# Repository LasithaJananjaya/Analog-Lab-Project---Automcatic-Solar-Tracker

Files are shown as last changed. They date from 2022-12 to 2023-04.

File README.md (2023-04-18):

# lab_project_solar_tracker
Semester 3 Analog Lab Project - Automatic Solar Tracker

## Abstract
This project aims to address the challenge of optimizing solar panel energy generation, given that the efficiency of current solar technology is affected by the intensity of sunlight and angle of incidence. The demand for solar power has increased worldwide as a preferred green energy alternative to non-renewable energy sources. To achieve the highest efficiency, an analog PID control circuit is designed to dynamically adjust the angular position of a solar panel along a single axis. This will enable the panel to optimize its generation of electricity, even under varying lighting and positional circumstances.

## Introduction
In contemporary times, the global community has been fervently exploring alternative energy sources, with a keen focus on renewable sources that can mitigate the adverse environmental impact of traditional energy sources. Among the plethora of renewable energy sources, solar energy has emerged as one of the most abundant and clean sources of energy on the planet. The harnessing of solar energy can be achieved through two main methods, namely, photovoltaic (PV) cells and solar thermal systems. Solar panels, which typically contain multiple solar cells, are employed to generate electricity using solar energy. These panels are installed in locations that receive direct sunlight, such as rooftops or solar farms, which may contain millions of solar panel arrays in desert areas. The utilization of solar energy through these methods offers significant potential to contribute to sustainable development and reduce dependence on non-renewable energy sources. 

A significant challenge facing solar panel technology is the inherent limitation that the maximum efficiency can only be achieved when the panel receives direct sunlight, i.e. when light strikes the panel perpendicularly. This constraint restricts the optimal efficiency of the panel to specific time periods during the day when the angle of incidence of the sun’s rays is perpendicular to the panel.

To overcome this constraint and enhance the efficiency of solar panels throughout the day, automatic solar trackers have emerged as a potential solution. These trackers are designed to enable solar panels to automatically align with direct sunlight, thereby maximizing the energy capture potential of the panel.

The incorporation of automatic solar trackers represents a significant advance in solar panel technology, enabling panels to achieve greater efficiency and reducing the environmental impact of energy production. By automatically adjusting the panel’s orientation to align with the sun’s rays, solar trackers offer a practical and effective means of maximizing energy output and promoting sustainable energy practices.

## Functionality Description
First, the two **LDR sensors** sense the intensity of the light that directly falls on. According to those parameters the resistances of the two sensors are varied. According to the design, if the resistance values of the two sensors are equal, the panel should remain still and if there is a difference, the panel should turn accordingly to reduce that difference. The panel is rotated using a motor and the motor is driven by a **PWM Control Signal**. If the duty of the PWM signal is 50%, the motor is not driven. Otherwise, the motor is driven in the required direction. The smooth operation of the motor is ensured by the **PID Controller**.

## System model
### Block Diagram

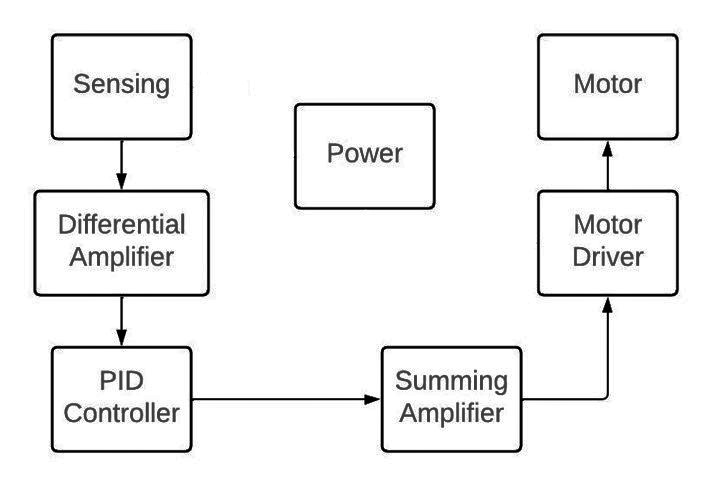
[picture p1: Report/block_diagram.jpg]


### Design Parameters
* Operating Voltage - 12 V
* Reference Voltage - 6 V
* Light Sensor - 12 mm LDR
* LDR Dark Resistance - 1MΩ
* LDR Light Resistance - 5 - 10 kΩ
* OPAMP Selection - UA741CP, LMC660CN and TLC372CP
* Motor Driver - L298N
* Motor - RK-370CA-18260 DC Motor
* Motor Stall Current - 300 mA
* PCB - 4 Layer, Manufactured and imported from JLC PCB (China)
* Enclosure Material - Wood

## Schematic

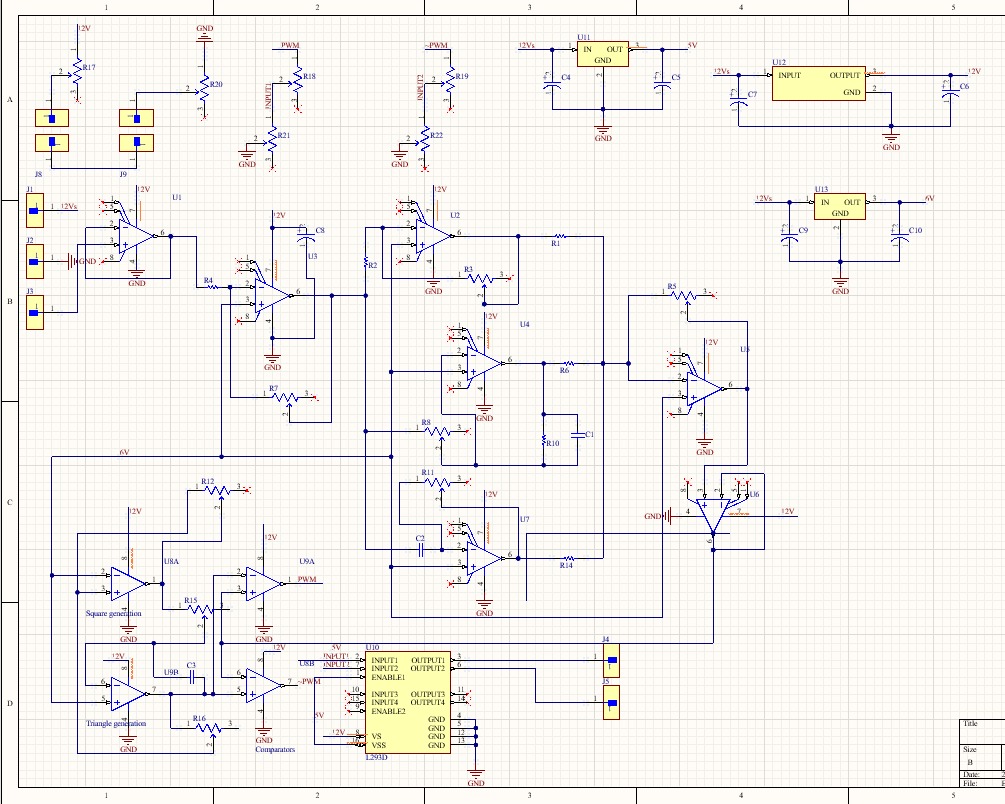
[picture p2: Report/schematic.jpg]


### Difference Amplifier
The difference between the input voltage and the set point voltage of 6 volts is being amplified

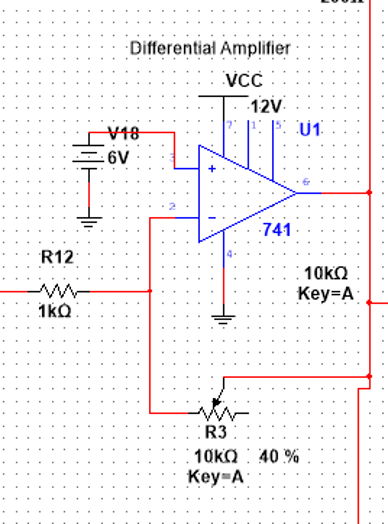
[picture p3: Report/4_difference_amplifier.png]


### PID Controller - Proportional Part

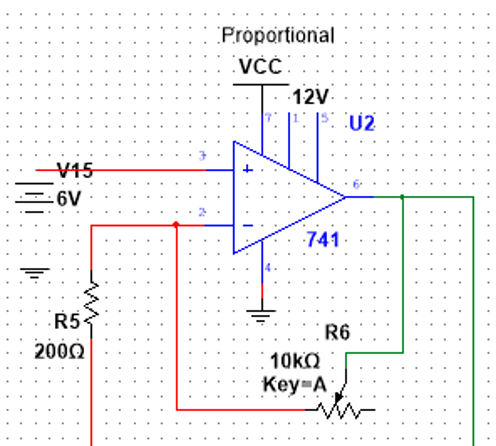
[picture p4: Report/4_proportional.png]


### PID Controller - Integral Part

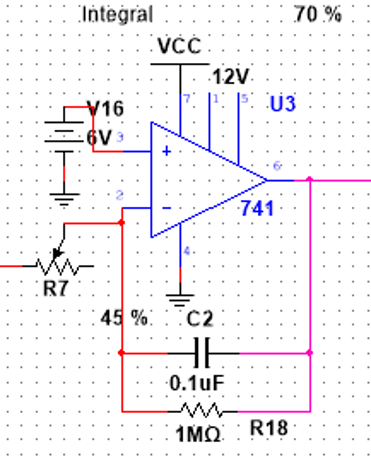
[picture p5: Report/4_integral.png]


### PID Controller - Derivative Part

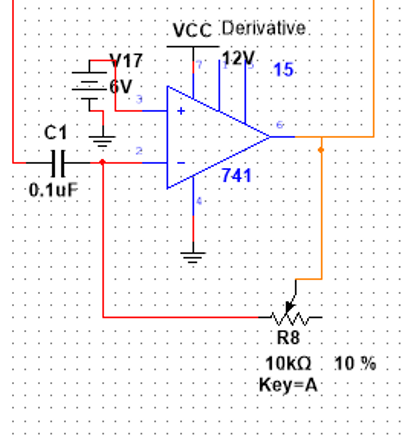
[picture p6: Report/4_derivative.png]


### Weighted Summing Amplifier
The Proportional-Integral-Derivative (PID) controller outputs are weighted and combined using appropriate algorithm. Specifically, larger resistors are incorporated into the design of the I and D controllers to ensure their effect on the overall operation of the PID controller is suitably reduced. This measure is essential for achieving a stable and effective PID control system.

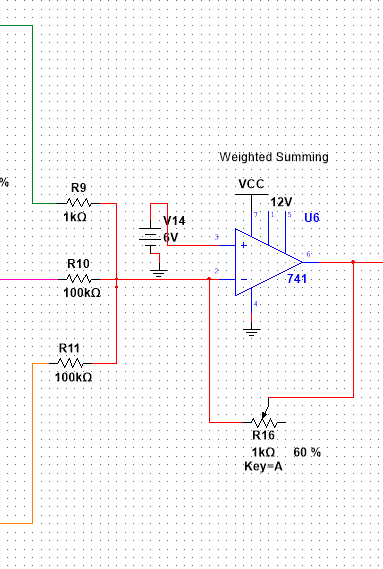
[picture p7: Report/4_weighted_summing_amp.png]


### Voltage Buffers
Voltage buffers have been employed to provide isolation between the input stage and output stage. To accomplish this, we have utilized an operational amplifier with a higher input impedance. This strategic implementation aims to minimize the loading effect and signal distortion that may occur between the two stages, thus ensuring optimal performance of the circuit. The incorporation of voltage buffers and an operational amplifier with higher input impedance serves to enhance the overall reliability and robustness of the circuit, while simultaneously minimizing potential signal loss and distortion.

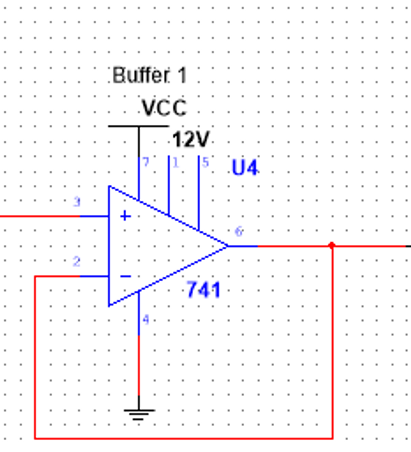
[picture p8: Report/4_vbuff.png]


### Triangular Wave Generation
The generation of a triangular waveform within the range of 0-12V and with a frequency of 500Hz is accomplished through the utilization of a Schmitt trigger and an integrator circuit. Specifically, the frequency of the waveform is tailored through the adjustment of resistor R13, which serves as a key variable in the control of the wave form’s frequency. Additionally, the threshold voltage is adjusted by maintaining a ratio of approximately unity between resistors R2 and R17, thereby ensuring that a nearly uniform amplitude variation of 0-12V is achievable.

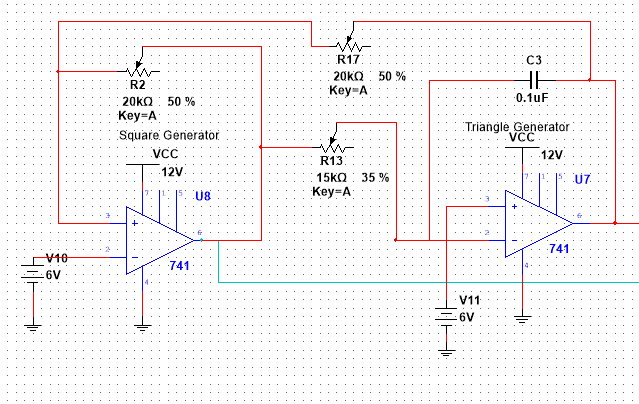
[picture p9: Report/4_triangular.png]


### PWM Generation
The pulse-width modulation (PWM) waves, which correspond to the control signal generated by the PID controller, are synthesized by the comparator through the utilization of a triangular waveform.

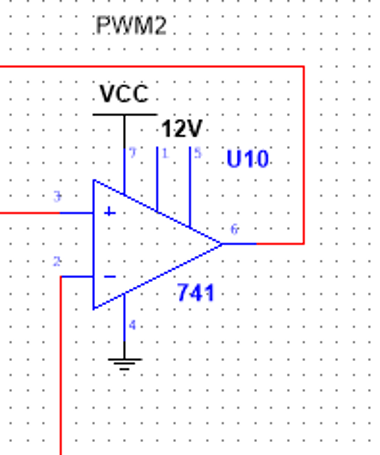
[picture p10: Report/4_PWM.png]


## PCB design
The Printed Circuit Board (PCB) comprises a total of four layers, of which the Top and Bottom layers function as two distinct signal layers. An additional layer is dedicated to ground pour, while another accommodates 12V and 6V pours, thereby providing a comprehensive and multifaceted platform for the effective transmission and distribution of electrical signals. The use of these multiple layers not only ensures the efficient utilization of space on the PCB but also facilitates the effective management of electrical energy, thereby enhancing the overall functionality and reliability of the circuitry without any effect of unnecessary noise.

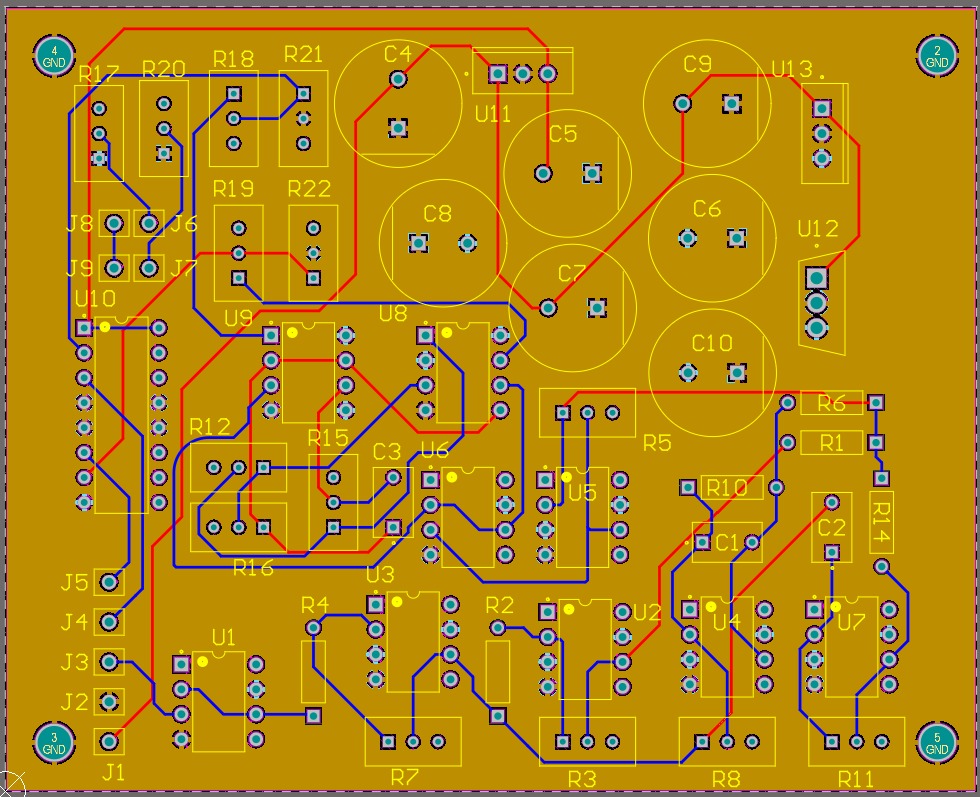
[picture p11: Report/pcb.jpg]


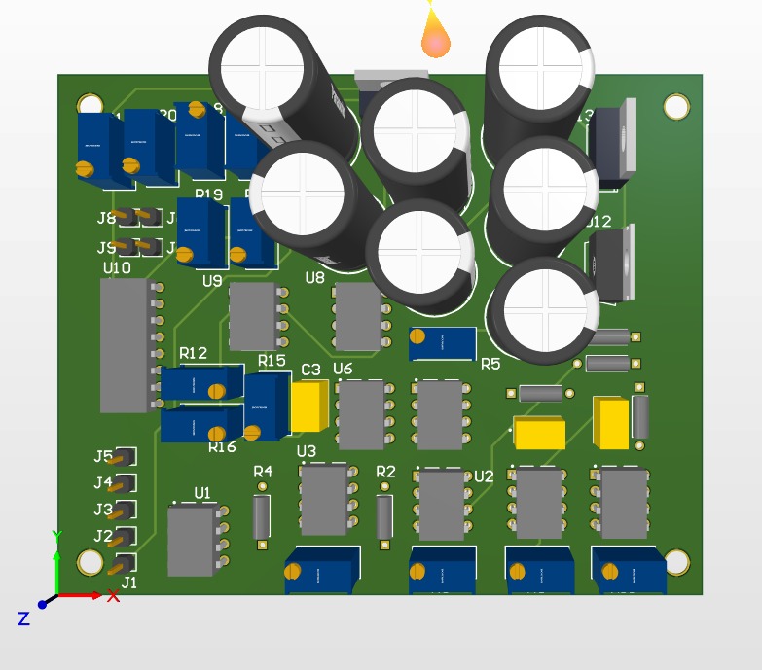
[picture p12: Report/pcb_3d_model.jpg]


### Top Layer

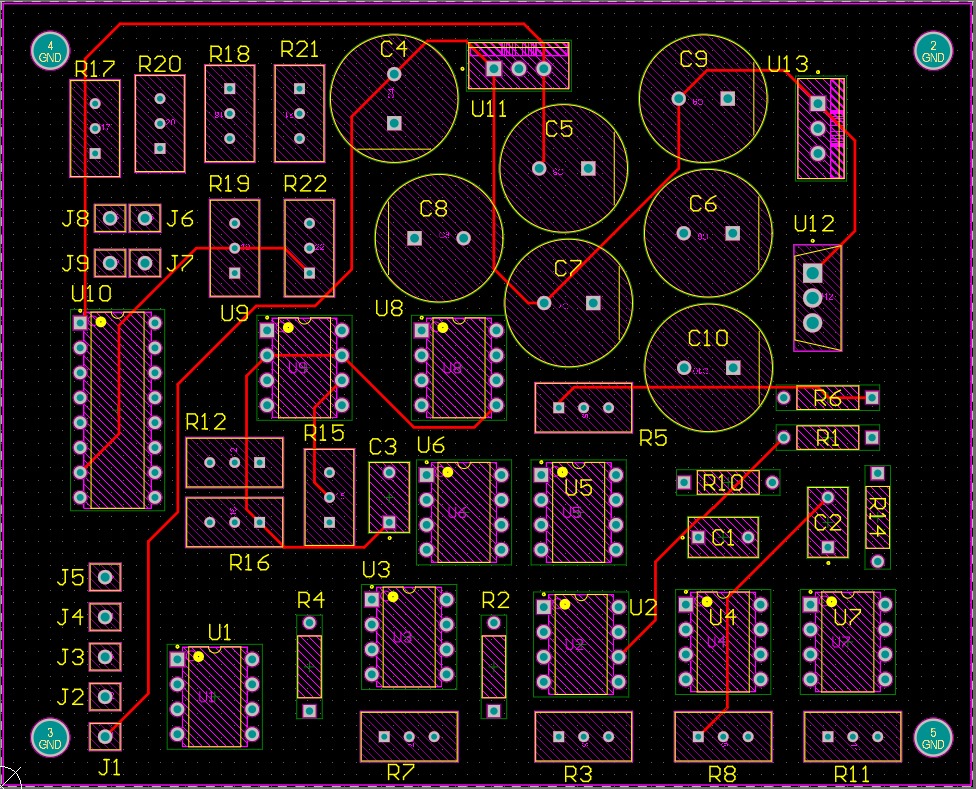
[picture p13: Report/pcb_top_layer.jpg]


### Bottom Layer

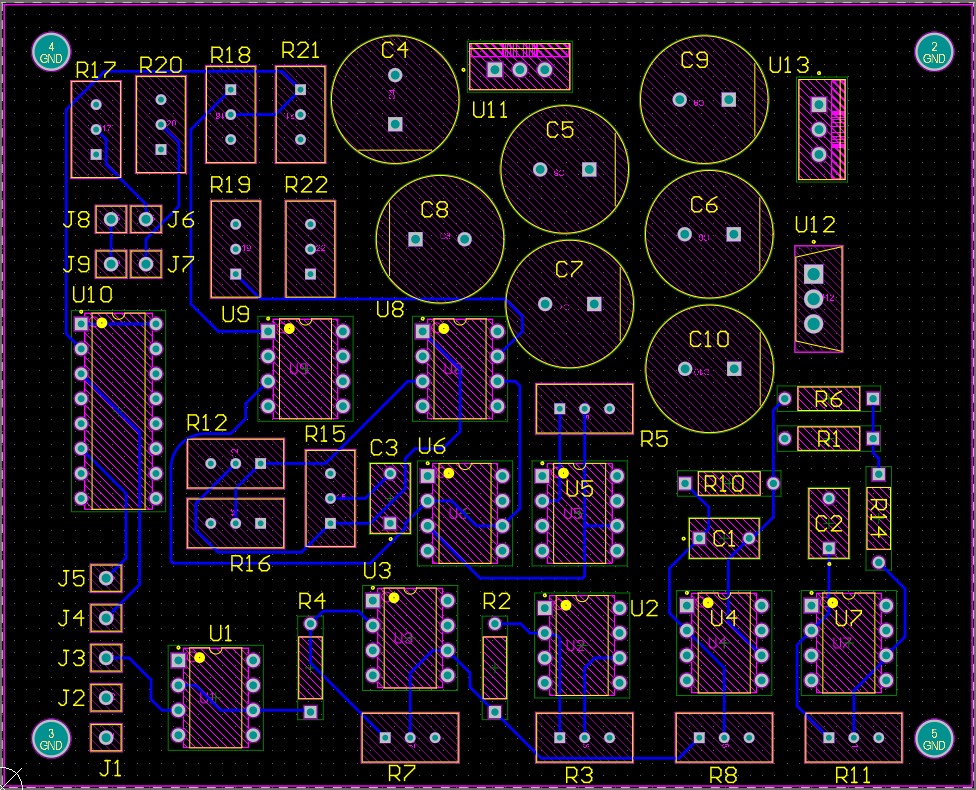
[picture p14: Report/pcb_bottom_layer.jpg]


### Layer 1

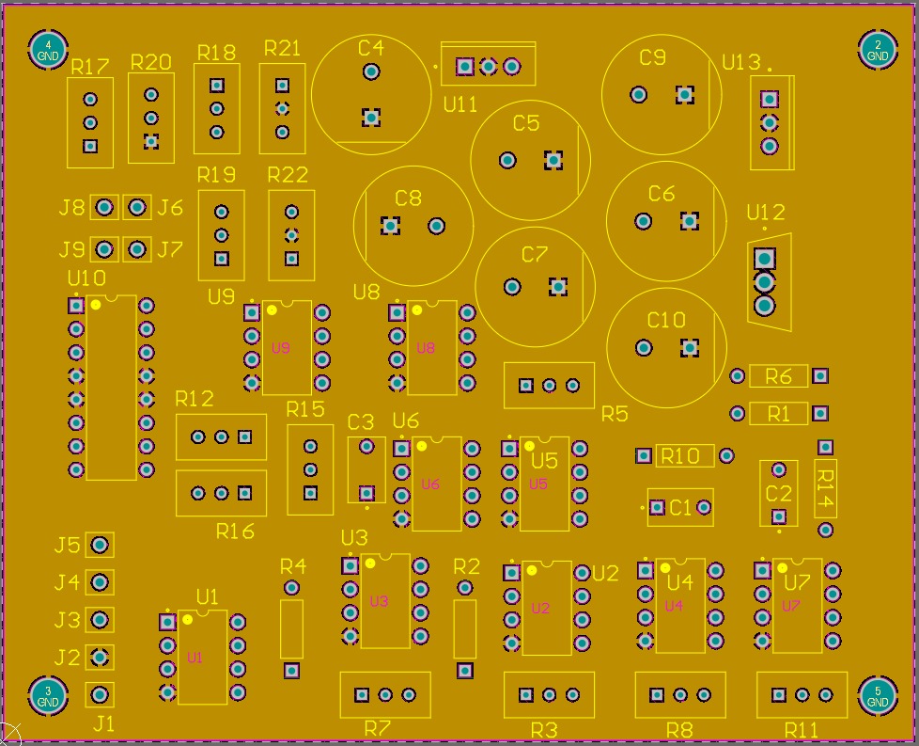
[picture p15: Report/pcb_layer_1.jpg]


### Layer 2

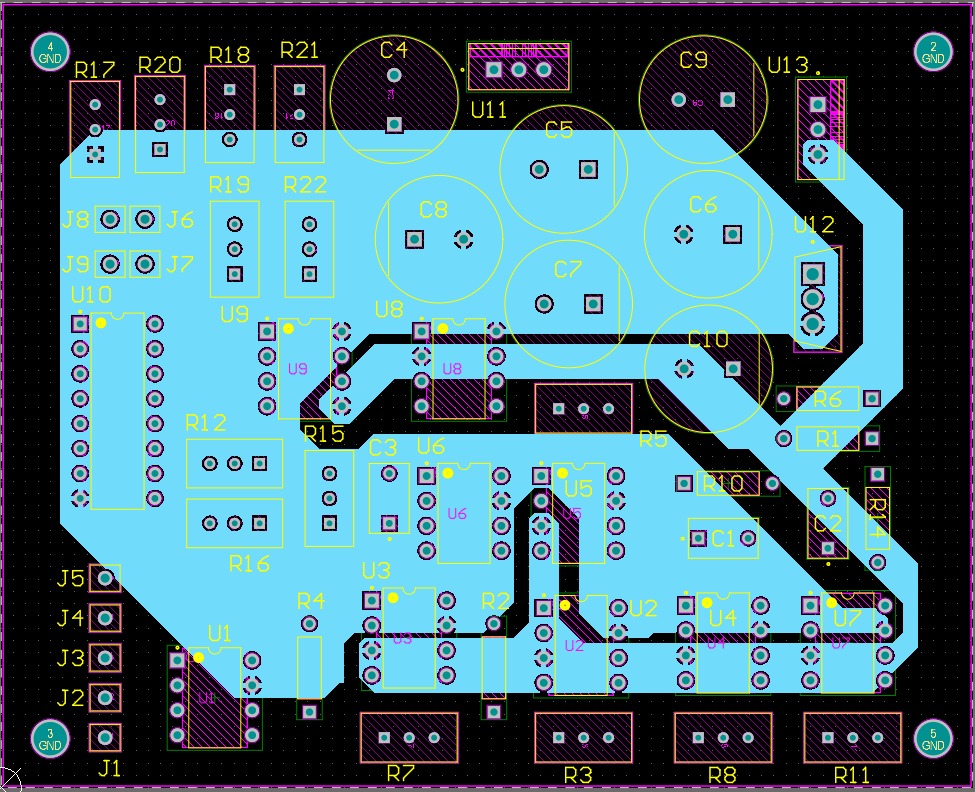
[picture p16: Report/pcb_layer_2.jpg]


## Enclosure design
The base of the structure measures 30cm x 10cm x 1cm and is designed to be affixed to a surface using screws. The entire assembly consists of the structure that holds the solar panel, motor, and printed circuit board (PCB). The solar panel is fixed to a frame that is supported by two arms, which have dimensions of 26cm x 5cm x 1cm. These arms are inserted into specially designed grooves in the base and secured in place with glue. A rod is used to secure the frame, and the motor, along with the PCB box, is attached to one of the arms using screws. The motor is directly connected to the rod, allowing the frame to rotate. The rod has a diameter of 1cm and a length of 30cm. The frame itself has an inner edge dimension of 30cm x 20cm and an outer edge dimension of 24cm x 14cm. Two light-dependent resistors (LDR) sensors are connected to the distant edges of the frame, which holds the solar panel. Two cylindrical structures with a diameter of 8mm and a height of 15mm are used to cover the LDR sensors, preventing sunlight from hitting the sensors from directions other than perpendicular to the sensor surface. The enclosure of the device is made of wood, and laser cutting is used for manufacturing. The wood panels used are of thickness 6mm and 4mm, and the screw nails used are of 3mm in diameter and 1.5 inches in length. Additionally, the enclosure is designed to hold the PCB and has a hole with a diameter of 2cm to accommodate the wires.

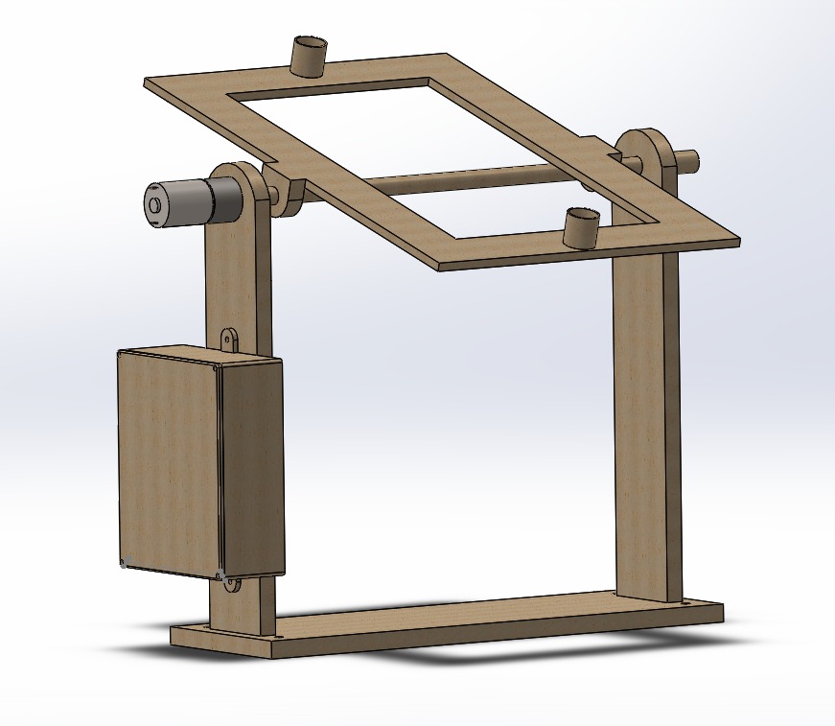
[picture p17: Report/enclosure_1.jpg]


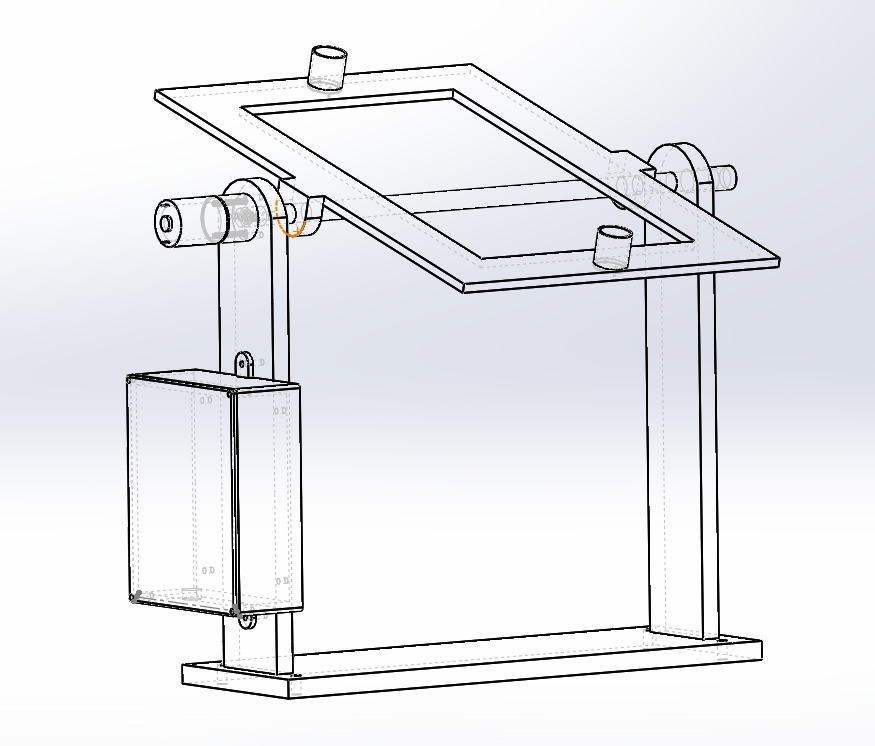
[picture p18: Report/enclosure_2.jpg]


## Conclusion and Future Works
Further tuning of the system is necessary to optimize its performance. Given that the system draws a relatively low power of approximately 1.4 W, it is feasible to explore the potential of powering it with a solar panel. To achieve this objective, it is recommended to incorporate a motor driver with a higher current capacity to accommodate the increased power demands of the system. Additionally, the inclusion of a Buck converter can significantly reduce power wastage and improve the system’s overall energy efficiency. These enhancements are critical to ensuring the sustainable and effective operation of the system and reducing its environmental impact.

## Acknowledgements
We would like to express our deepest appreciation and gratitude to the project supervisors for their invaluable contributions and unwavering support in the successful completion of this report. Their profound expertise, meticulous guidance, and astute insights have been pivotal in ensuring the excellence and effectiveness of this project. Furthermore, we extend our heartfelt thanks to our esteemed colleagues and team members for their unwavering dedication, exceptional competence, and tireless efforts in bringing this project to fruition. Their unrelenting commitment and teamwork have been crucial in overcoming the numerous challenges and obstacles encountered throughout the project’s execution.

In conclusion, we recognize and acknowledge the significant contributions of all those involved in this project, and we remain deeply grateful for their unwavering support, dedication, and commitment to the success of this endeavour.

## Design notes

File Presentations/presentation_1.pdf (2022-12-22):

# Analog Solar Tracker Project Group 10

December 21, 2022

1 | Sensing
2 | Differential Amplifier
3 | PID controller
4 | Linear Amplifier
5 | Motor

# Blocks

# Sensing

These are the sensors that we use to measure the amount of light falling on the solar panel. These need to be accurate and have a low response time.

Options Available

LDR | Photodiode
We can create a potential divider by using two series LDR. So we might get a voltage value as the output of the sensing part. So, we can give it as a input to our op-amp comparator. | Here we'll get a current which is propotinal to the sensing input. So we can't input this to our op-amp.
Response time is relatively high which makes it quite slow. | Response time is relatively less than that of the LDR.
Which and How many ? | LDR - 2
Placement | On 2 opposite edges(which are parallel to the axis of rotation) of the solar panel.
5 mm, 12 mm or 20 mm | Yet to be decided

# Differential Amplifier

We use a differential amplifier to get the difference between the set-point of our choice and sensed output from the sensors. We use the 2 LDRs in a potential divider circuit and we get the voltage in the point in the middle of the 2 LDRs. As it is easier to make the set point zero, we design the potential divider circuit in such a manner where, if the resistance of the 2 LDRs are equal, the voltage of the point in the middle of the 2 sensors become zero.

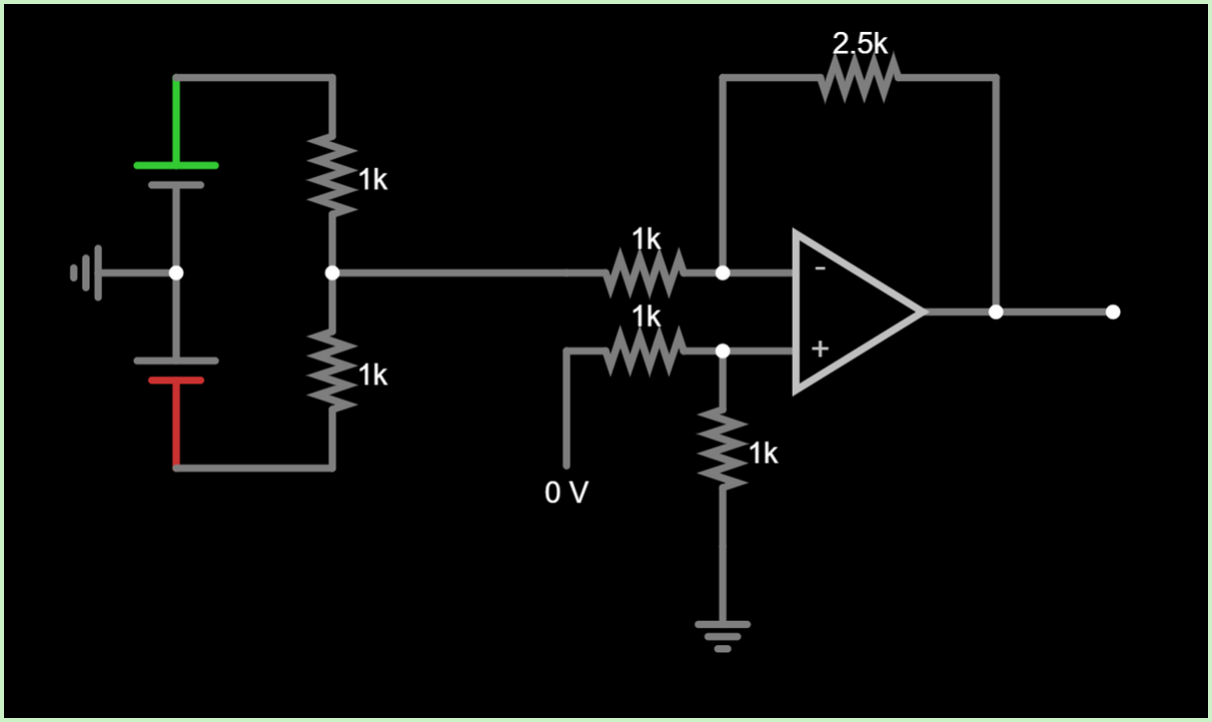
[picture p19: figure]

# PID Controller

First of all we had to decide whether all the 3 parts of a PID controller is required for this design.

Propotional part | This part is a must.
Integral part | The proportional part cannot lower the difference than some value.
Derivative part | Overshooting might be an issue. Therefore this was needed.

# Linear Amplifier

The output current from the PID controller is not enough to drive a dc motor. Therefore the current needed to be amplified while the voltage output of the PID controller remained the same.

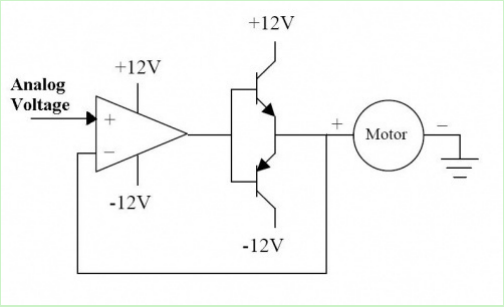
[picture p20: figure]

# Motor

As we are required to present a design with maximum efficiency, we had to consider the available options for a motor.

Options Available

DC | Servo | Stepper
An analog signal is enough to drive the motor. A current and a voltage of a considerable amount is required. | PWM | PWM
Not quite efficient | Efficient | Efficient
Fast, Continuous Rotation, High RPM | Fast, High torque, Accurate rotation within a limited angle | Slow, Precise rotation (Accuracy is better than servo motors)

Our decision is to use a DC motor

The operating voltage of the DC motor is yet to be decided. (Roughly 10 V)

Less complexity of driving the motor, since PWM is not used.

# Thank You!

December 21, 2022

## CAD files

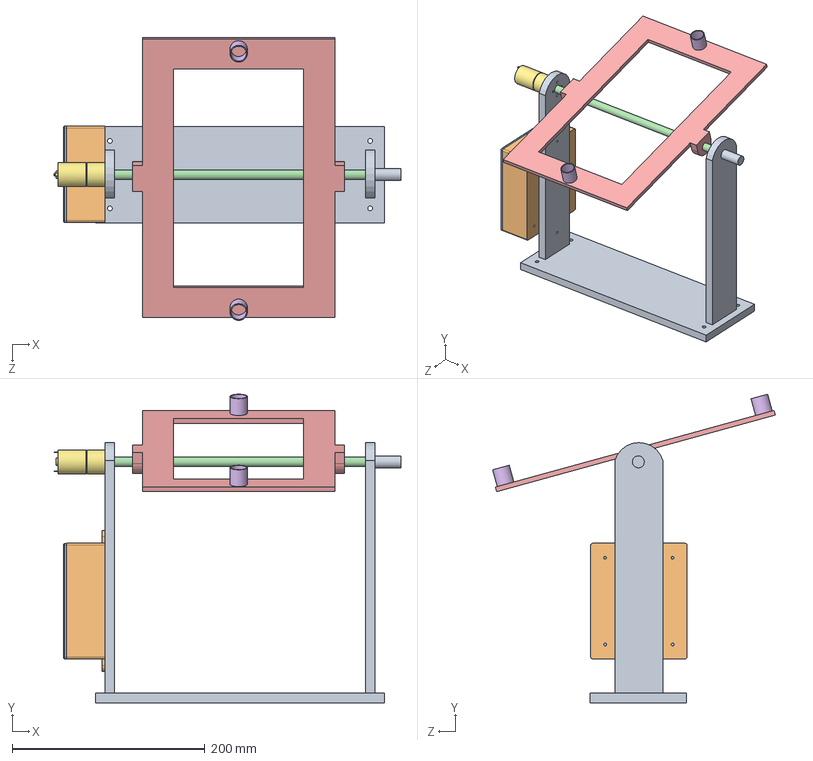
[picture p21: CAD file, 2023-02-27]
Solidwork Files/solar_tracker_2.SLDASM
360.0 x 320.2 x 293.4 mm
Base2
PCB_box2
pcb_lid2
Pin2
frame2
LDR_cover2 x 2
EconomyGearmotorServocity

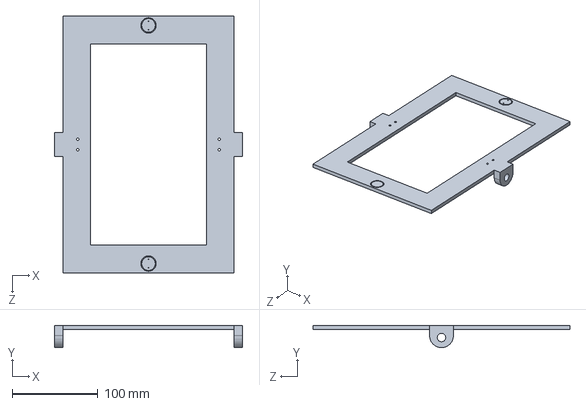
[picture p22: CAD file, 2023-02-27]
Solidwork Files/frame2.SLDPRT
220.0 x 25.9 x 300.0 mm

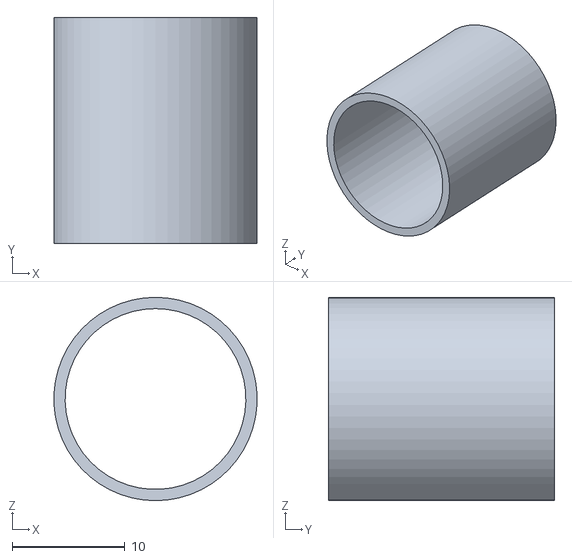
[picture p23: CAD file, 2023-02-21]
Solidwork Files/PRINT/LDR_cover2_2.STL
18.0 x 20.0 x 18.0

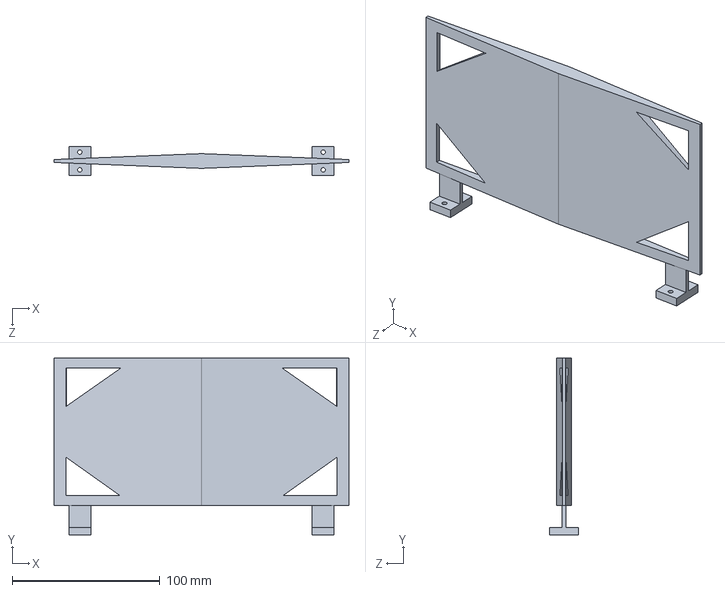
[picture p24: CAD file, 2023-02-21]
Solidwork Files/Plate2.SLDPRT
200.0 x 120.0 x 20.0 mm

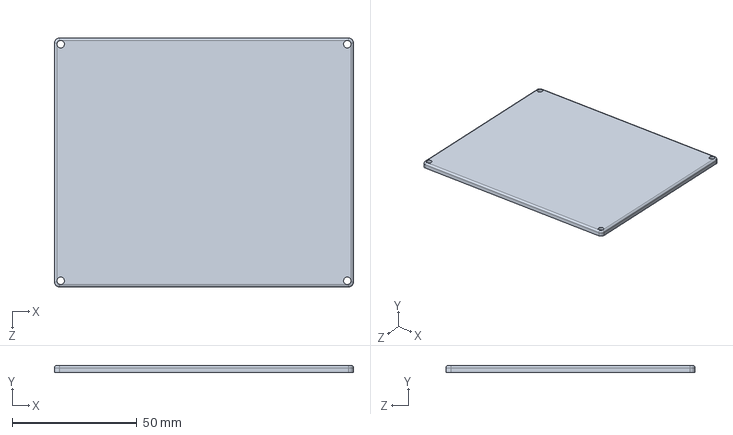
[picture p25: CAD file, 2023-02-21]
Solidwork Files/pcb_lid2.SLDPRT
120.0 x 3.00 x 100.0 mm

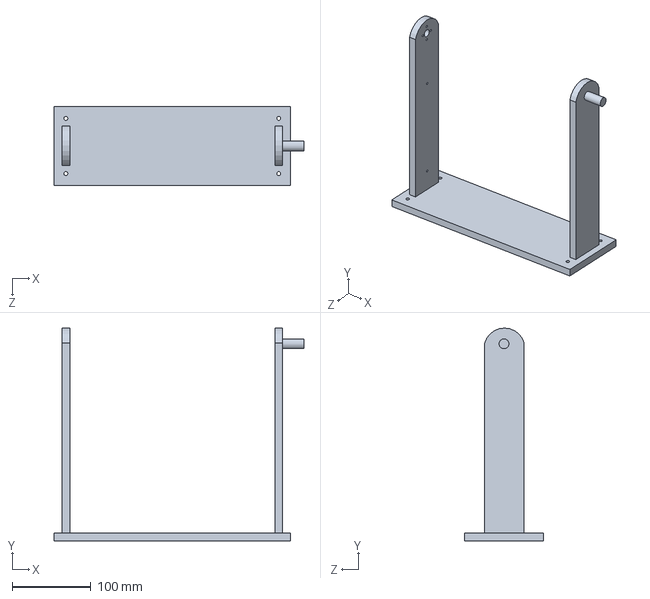
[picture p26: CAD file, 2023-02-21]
Solidwork Files/Base2.SLDPRT
317.0 x 270.0 x 100.0 mm

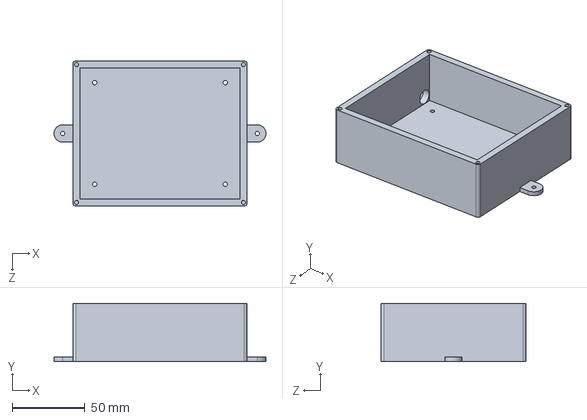
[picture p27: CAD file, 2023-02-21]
Solidwork Files/PCB_box2.SLDPRT
146.0 x 40.0 x 100.0 mm

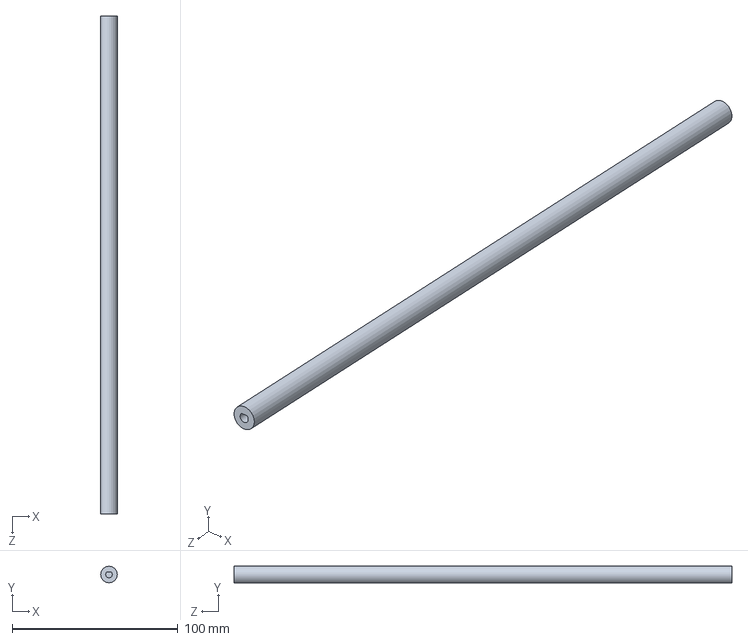
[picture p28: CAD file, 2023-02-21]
Solidwork Files/Pin2.SLDPRT
10.0 x 10.0 x 300.0 mm

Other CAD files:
Solidwork Files/PRINT/LDR_cover2_1.STL
Solidwork Files/LDR_cover2.SLDPRT
Solidwork Files/PRINT/Base2.STL
Solidwork Files/PRINT/PCB_box2.STL
Solidwork Files/PRINT/Pin2.STL
Solidwork Files/PRINT/Plate2.STL
Solidwork Files/PRINT/frame2.STL
Solidwork Files/PRINT/pcb_lid2.STL

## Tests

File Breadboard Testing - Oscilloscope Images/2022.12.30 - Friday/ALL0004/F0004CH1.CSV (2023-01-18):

Record Length | 2.500000e+03 | -0.002500000000 | -5.20000
Sample Interval | 2.000000e-06 | -0.002498000000 | -5.20000
Trigger Point | 1.250000000000e+03 | -0.002496000000 | -5.20000
 |  | -0.002494000000 | -5.20000
 |  | -0.002492000000 | -5.20000
 |  | -0.002490000000 | -5.20000
Source | CH1 | -0.002488000000 | -5.20000
Vertical Units | V | -0.002486000000 | -5.20000
Vertical Scale | 5.000000e+00 | -0.002484000000 | -5.20000
Vertical Offset | -2.000000e-01 | -0.002482000000 | -5.20000
Horizontal Units | s | -0.002480000000 | -5.20000
Horizontal Scale | 5.000000e-04 | -0.002478000000 | -5.20000
Pt Fmt | Y | -0.002476000000 | -5.20000
Yzero | 0.000000e+00 | -0.002474000000 | -5.20000
Probe Atten | 1.000000e+01 | -0.002472000000 | -5.20000
Model Number | TBS1052B | -0.002470000000 | -5.20000
Serial Number | C024004 | -0.002468000000 | -5.40000
Firmware Version | FV:v4.06 | -0.002466000000 | -5.40000
 |  | -00.002464000000 | -5.20000
 |  | -00.002462000000 | -5.40000
 |  | -00.002460000000 | -5.20000
 |  | -00.002458000000 | -5.40000
 |  | -00.002456000000 | -5.40000
 |  | -00.002454000000 | -5.20000
 |  | -00.002452000000 | -5.40000
 |  | -00.002450000000 | -5.40000
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

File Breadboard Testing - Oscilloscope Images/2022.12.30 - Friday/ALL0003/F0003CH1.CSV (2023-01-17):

Record Length | 2.500000e+03 | -0.002500000000 | -0.20000
Sample Interval | 2.000000e-06 | -0.002498000000 | -0.20000
Trigger Point | 1.250000000000e+03 | -0.002496000000 | -0.20000
 |  | -0.002494000000 | -0.20000
 |  | -0.002492000000 | -0.20000
 |  | -0.002490000000 | -0.20000
Source | CH1 | -0.002488000000 | -0.20000
Vertical Units | V | -0.002486000000 | -0.20000
Vertical Scale | 5.000000e+00 | -0.002484000000 | -0.20000
Vertical Offset | -2.000000e-01 | -0.002482000000 | -0.20000
Horizontal Units | s | -0.002480000000 | -0.40000
Horizontal Scale | 5.000000e-04 | -0.002478000000 | -0.20000
Pt Fmt | Y | -0.002476000000 | -0.20000
Yzero | 0.000000e+00 | -0.002474000000 | -0.40000
Probe Atten | 1.000000e+01 | -0.002472000000 | -0.20000
Model Number | TBS1052B | -0.002470000000 | -0.20000
Serial Number | C024004 | -0.002468000000 | -0.20000
Firmware Version | FV:v4.06 | -0.002466000000 | -0.20000
 |  | -00.002464000000 | -0.20000
 |  | -00.002462000000 | -0.20000
 |  | -00.002460000000 | -0.20000
 |  | -00.002458000000 | -0.40000
 |  | -00.002456000000 | -0.40000
 |  | -00.002454000000 | -0.20000
 |  | -00.002452000000 | -0.20000
 |  | -00.002450000000 | -0.40000
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

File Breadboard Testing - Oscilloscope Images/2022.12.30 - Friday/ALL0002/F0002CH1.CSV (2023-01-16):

Record Length | 2.500000e+03 | -0.002500000000 | 0.40000
Sample Interval | 2.000000e-06 | -0.002498000000 | 0.20000
Trigger Point | 1.250000000000e+03 | -0.002496000000 | 0.40000
 |  | -0.002494000000 | 0.40000
 |  | -0.002492000000 | 0.40000
 |  | -0.002490000000 | 0.40000
Source | CH1 | -0.002488000000 | 0.40000
Vertical Units | V | -0.002486000000 | 0.40000
Vertical Scale | 5.000000e+00 | -0.002484000000 | 0.40000
Vertical Offset | -2.000000e-01 | -0.002482000000 | 0.40000
Horizontal Units | s | -0.002480000000 | 0.40000
Horizontal Scale | 5.000000e-04 | -0.002478000000 | 0.40000
Pt Fmt | Y | -0.002476000000 | 0.20000
Yzero | 0.000000e+00 | -0.002474000000 | 0.20000
Probe Atten | 1.000000e+01 | -0.002472000000 | 0.40000
Model Number | TBS1052B | -0.002470000000 | 0.40000
Serial Number | C024004 | -0.002468000000 | 0.40000
Firmware Version | FV:v4.06 | -0.002466000000 | 0.40000
 |  | -00.002464000000 | 0.40000
 |  | -00.002462000000 | 0.40000
 |  | -00.002460000000 | 0.40000
 |  | -00.002458000000 | 0.40000
 |  | -00.002456000000 | 0.20000
 |  | -00.002454000000 | 0.40000
 |  | -00.002452000000 | 0.40000
 |  | -00.002450000000 | 0.40000
 |  | -00.002448000000 | 0.60000
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

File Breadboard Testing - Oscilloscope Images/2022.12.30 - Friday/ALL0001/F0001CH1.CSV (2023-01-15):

Record Length | 2.500000e+03 | -0.002500000000 | -6.40000
Sample Interval | 2.000000e-06 | -0.002498000000 | -7.20000
Trigger Point | 1.250000000000e+03 | -0.002496000000 | -8.00000
 |  | -0.002494000000 | -8.00000
 |  | -0.002492000000 | -8.00000
 |  | -0.002490000000 | -8.00000
Source | CH1 | -0.002488000000 | -8.00000
Vertical Units | V | -0.002486000000 | -8.00000
Vertical Scale | 5.000000e+00 | -0.002484000000 | -8.00000
Vertical Offset | -2.000000e-01 | -0.002482000000 | -8.00000
Horizontal Units | s | -0.002480000000 | -8.00000
Horizontal Scale | 5.000000e-04 | -0.002478000000 | -8.00000
Pt Fmt | Y | -0.002476000000 | -8.20000
Yzero | 0.000000e+00 | -0.002474000000 | -8.00000
Probe Atten | 1.000000e+01 | -0.002472000000 | -8.00000
Model Number | TBS1052B | -0.002470000000 | -8.00000
Serial Number | C024004 | -0.002468000000 | -8.00000
Firmware Version | FV:v4.06 | -0.002466000000 | -8.00000
 |  | -00.002464000000 | -8.00000
 |  | -00.002462000000 | -8.00000
 |  | -00.002460000000 | -7.80000
 |  | -00.002458000000 | -8.00000
 |  | -00.002456000000 | -8.00000
 |  | -00.002454000000 | -8.00000
 |  | -00.002452000000 | -8.00000
 |  | -00.002450000000 | -8.00000
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

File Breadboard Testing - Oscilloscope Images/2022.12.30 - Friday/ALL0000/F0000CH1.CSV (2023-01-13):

Record Length | 2.500000e+03 | -0.002500000000 | -5.80000
Sample Interval | 2.000000e-06 | -0.002498000000 | -5.80000
Trigger Point | 1.250000000000e+03 | -0.002496000000 | -6.00000
 |  | -0.002494000000 | -5.80000
 |  | -0.002492000000 | -5.80000
 |  | -0.002490000000 | -5.80000
Source | CH1 | -0.002488000000 | -5.80000
Vertical Units | V | -0.002486000000 | -5.80000
Vertical Scale | 5.000000e+00 | -0.002484000000 | -5.80000
Vertical Offset | -2.000000e-01 | -0.002482000000 | -5.80000
Horizontal Units | s | -0.002480000000 | -6.00000
Horizontal Scale | 5.000000e-04 | -0.002478000000 | -5.80000
Pt Fmt | Y | -0.002476000000 | -5.80000
Yzero | 0.000000e+00 | -0.002474000000 | -5.80000
Probe Atten | 1.000000e+01 | -0.002472000000 | -5.80000
Model Number | TBS1052B | -0.002470000000 | -5.80000
Serial Number | C024004 | -0.002468000000 | -5.80000
Firmware Version | FV:v4.06 | -0.002466000000 | -6.00000
 |  | -00.002464000000 | -5.80000
 |  | -00.002462000000 | -5.80000
 |  | -00.002460000000 | -5.80000
 |  | -00.002458000000 | -5.80000
 |  | -00.002456000000 | -5.80000
 |  | -00.002454000000 | -5.80000
 |  | -00.002452000000 | -5.60000
 |  | -00.002450000000 | -5.80000
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

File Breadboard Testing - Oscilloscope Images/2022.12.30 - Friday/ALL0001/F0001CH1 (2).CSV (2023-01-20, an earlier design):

Record Length | 2.500000e+03 | -0.002500000000 | 0.00000
Sample Interval | 2.000000e-06 | -0.002498000000 | 0.00000
Trigger Point | 1.250000000000e+03 | -0.002496000000 | 0.20000
 |  | -0.002494000000 | 0.20000
 |  | -0.002492000000 | 0.00000
 |  | -0.002490000000 | 0.00000
Source | CH1 | -0.002488000000 | 0.00000
Vertical Units | V | -0.002486000000 | 0.00000
Vertical Scale | 5.000000e+00 | -0.002484000000 | 0.20000
Vertical Offset | -2.000000e-01 | -0.002482000000 | 0.00000
Horizontal Units | s | -0.002480000000 | 0.20000
Horizontal Scale | 5.000000e-04 | -0.002478000000 | 0.20000
Pt Fmt | Y | -0.002476000000 | 0.00000
Yzero | 0.000000e+00 | -0.002474000000 | 0.00000
Probe Atten | 1.000000e+01 | -0.002472000000 | 0.00000
Model Number | TBS1052B | -0.002470000000 | 0.20000
Serial Number | C024004 | -0.002468000000 | 0.00000
Firmware Version | FV:v4.06 | -0.002466000000 | 0.20000
 |  | -00.002464000000 | 0.00000
 |  | -00.002462000000 | 0.00000
 |  | -00.002460000000 | 0.00000
 |  | -00.002458000000 | 0.00000
 |  | -00.002456000000 | -0.20000
 |  | -00.002454000000 | 0.00000
 |  | -00.002452000000 | 0.20000
 |  | -00.002450000000 | 0.00000
 |  | -00.002448000000 | 0.00000
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

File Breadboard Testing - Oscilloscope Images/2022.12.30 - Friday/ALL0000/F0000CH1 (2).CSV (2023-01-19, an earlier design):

Record Length | 2.500000e+03 | -0.002500000000 | 0.00000
Sample Interval | 2.000000e-06 | -0.002498000000 | 0.20000
Trigger Point | 1.250000000000e+03 | -0.002496000000 | 0.20000
 |  | -0.002494000000 | 0.00000
 |  | -0.002492000000 | 0.20000
 |  | -0.002490000000 | 0.20000
Source | CH1 | -0.002488000000 | 0.20000
Vertical Units | V | -0.002486000000 | 0.00000
Vertical Scale | 5.000000e+00 | -0.002484000000 | 0.20000
Vertical Offset | -2.000000e-01 | -0.002482000000 | 0.00000
Horizontal Units | s | -0.002480000000 | 0.00000
Horizontal Scale | 5.000000e-04 | -0.002478000000 | 0.20000
Pt Fmt | Y | -0.002476000000 | 0.20000
Yzero | 0.000000e+00 | -0.002474000000 | 0.00000
Probe Atten | 1.000000e+01 | -0.002472000000 | 0.00000
Model Number | TBS1052B | -0.002470000000 | 0.20000
Serial Number | C024004 | -0.002468000000 | 0.00000
Firmware Version | FV:v4.06 | -0.002466000000 | 0.20000
 |  | -00.002464000000 | 0.20000
 |  | -00.002462000000 | 0.00000
 |  | -00.002460000000 | 0.00000
 |  | -00.002458000000 | 0.00000
 |  | -00.002456000000 | 0.00000
 |  | -00.002454000000 | 0.20000
 |  | -00.002452000000 | 0.00000
 |  | -00.002450000000 | 0.00000
 |  | -00.002448000000 | 0.20000
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

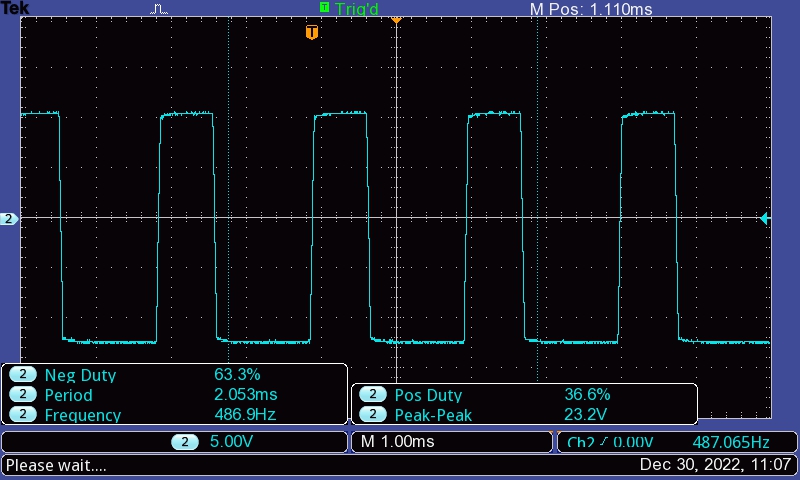
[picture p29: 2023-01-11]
Breadboard Testing - Oscilloscope Images/2022.12.30 - Friday/F0004TEK.JPG

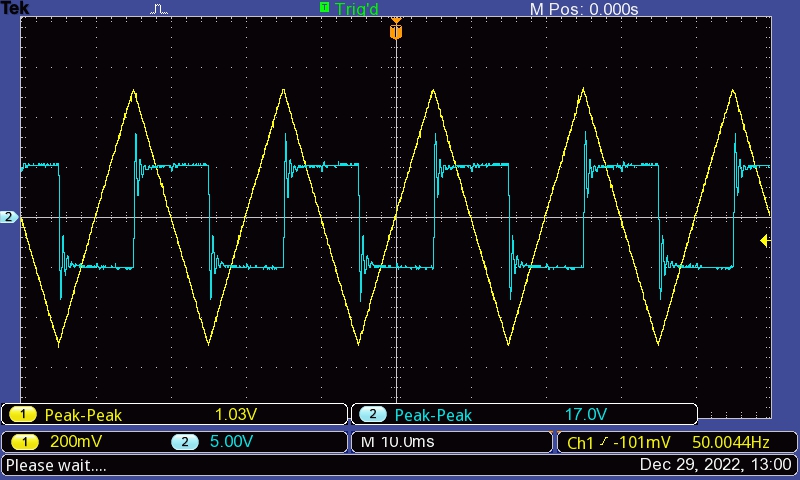
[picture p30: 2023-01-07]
Breadboard Testing - Oscilloscope Images/2022.12.29 - Thursday/TEK0012.JPG

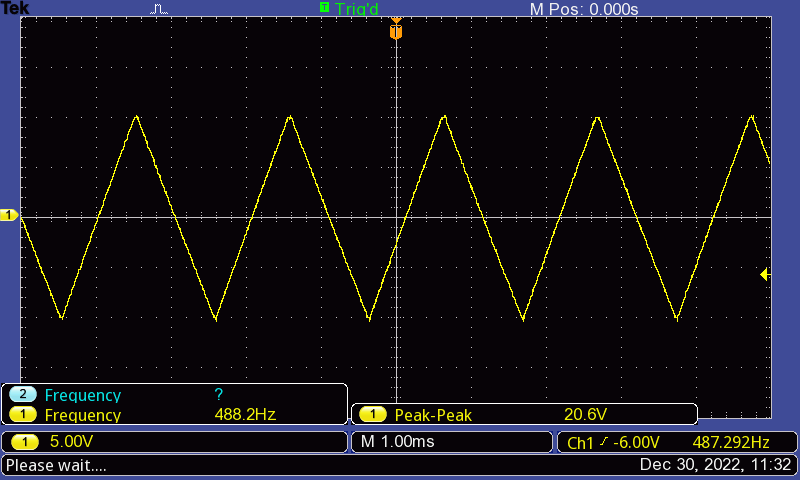
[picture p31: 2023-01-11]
Breadboard Testing - Oscilloscope Images/2022.12.30 - Friday/F0003TEK.BMP

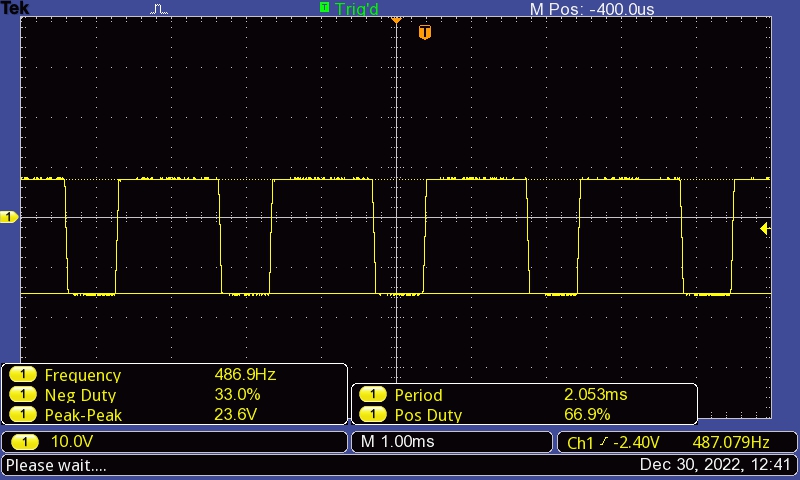
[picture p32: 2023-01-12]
Breadboard Testing - Oscilloscope Images/2022.12.30 - Friday/TEK0003.JPG

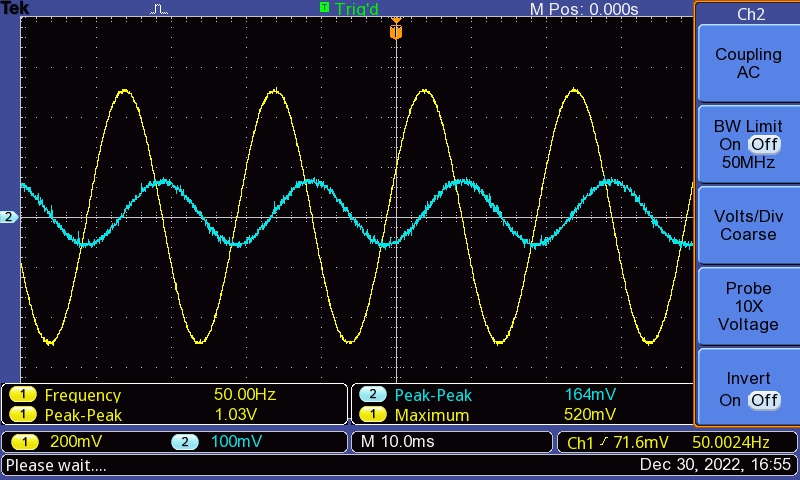
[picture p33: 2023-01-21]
Breadboard Testing - Oscilloscope Images/2023.01.02 -Tuesday/TEK0004.JPG

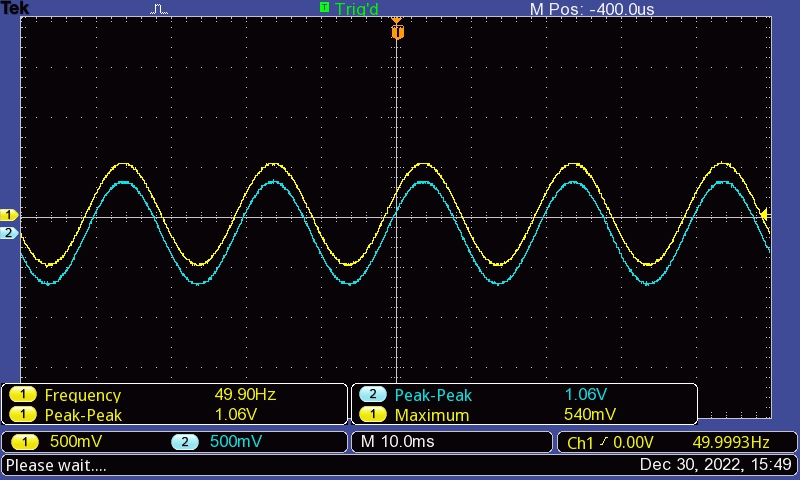
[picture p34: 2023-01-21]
Breadboard Testing - Oscilloscope Images/2023.01.02 -Tuesday/TEK0000.JPG

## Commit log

2023-01-13 friday - 3 - 0
    [F0000CH1.CSV]
2023-01-15 friday - 3 - 1
    [F0001CH1.CSV]
2023-01-16 friday - 3 - 2
    [F0002CH1.CSV]
2023-01-17 friday 3 - 3
    [F0003CH1.CSV]
2023-01-18 friday - 3 - 4
    [F0004CH1.CSV]
2023-01-19 friday - 4 - 0
    [F0000CH1 (2).CSV]
2023-01-20 friday - 4 - 1
    [F0001CH1 (2).CSV]
2023-02-27 solidworks final
    [frame2.SLDPRT, solar_tracker_2.SLDASM]
2023-02-28 altium files
    [AltiumPCB.PcbDoc, AltiumSchematicSheet.SchDoc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]
